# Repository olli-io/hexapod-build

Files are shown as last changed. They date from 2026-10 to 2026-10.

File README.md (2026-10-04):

# hexapod-build

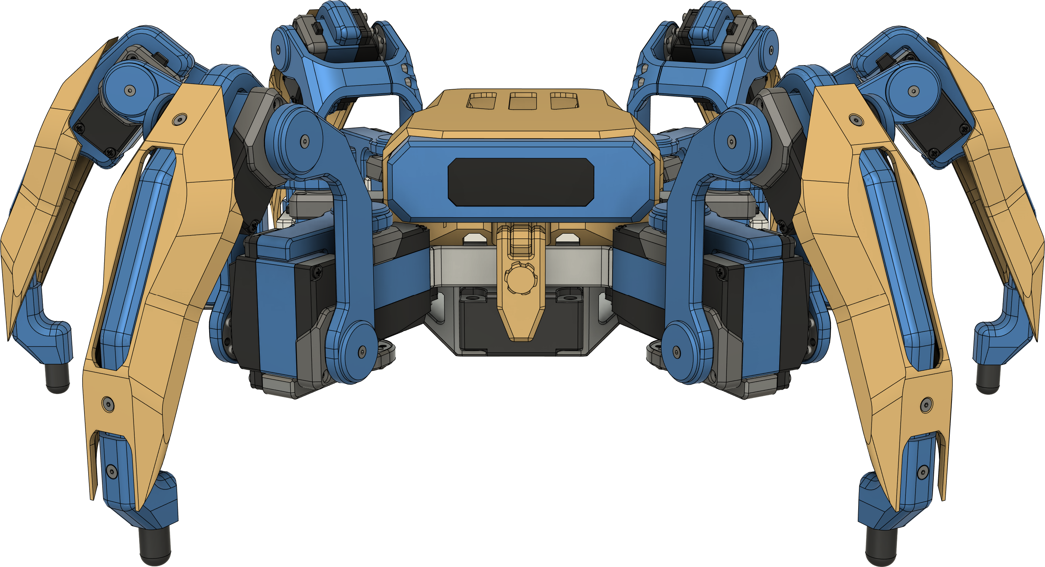
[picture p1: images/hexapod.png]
Hexapod render


## Introduction

This is the main build repository for a hexapod I've designed and built. This and the two companion repositories contain instructions to build and drive the hexapod.

> [!WARNING]
> This is a challenging, purely DIY project. Use these instructions at you own risk. There is no support, warranty or throubleshooting help. If you want to build it, be prepared to do figure out any issues you may run into yourself.
>
> NOTE: A simpler/cheaper build is in the works using a Pi Pico 2 W instead of a rasperry pi.

The hexapod can be controlled with an xbox (or equivalent) controller or a webapp hosted via wifi on the rasperry pi running the robot.

## Resources 

- [`instructions`](instructions-v1.0.0.pdf) - Build instructions
- [`bill-of-materials`](bill-of-materials.md) - Parts list.
- [`prints/`](prints) - Print files (`.3mf`).
- [`cad/`](cad) - CAD models (`.step`).
- [Demo video](https://youtube.com/shorts/dI83HE2yN1Q) - Hexapod in action.

## Companion repositories

The hexapod software is hosted on two repositories, which contain instructions how to get the hexapod running.
- [olli-io/hexapod-ros2-control](https://github.com/olli-io/hexapod-ros2-control) — ROS 2 control stack for the 6-leg / 18-DOF hexapod. Runs in docker on a Raspberry Pi 5. Also includes a Gazebo sim container for linux.
- [olli-io/hexapod-servo2040-driver](https://github.com/olli-io/hexapod-servo2040-driver) — Firmware for the Pimoroni Servo 2040 (RP2040). Drives the 18 servos over UART.

## Contributions

I am open to contributions. Example: if you use your time to modify the leg parts to accomodate a servo with different dimensions, please let me know and we can add it to the repo.

The [MYP hexapod](https://github.com/MakeYourPet/hexapod) and [Aecert's hexapod](https://github.com/Ryan-Mirch/Aecerts_Hexapod_V1) are spiritual predecessors of this project. Ideas have been taken from both of these projects.

> [!NOTE]
> This work is licensed under the [Creative Commons Attribution-NonCommercial 4.0 International License (CC BY-NC 4.0)](https://creativecommons.org/licenses/by-nc/4.0/). See [`LICENSE`](LICENSE).

## Images

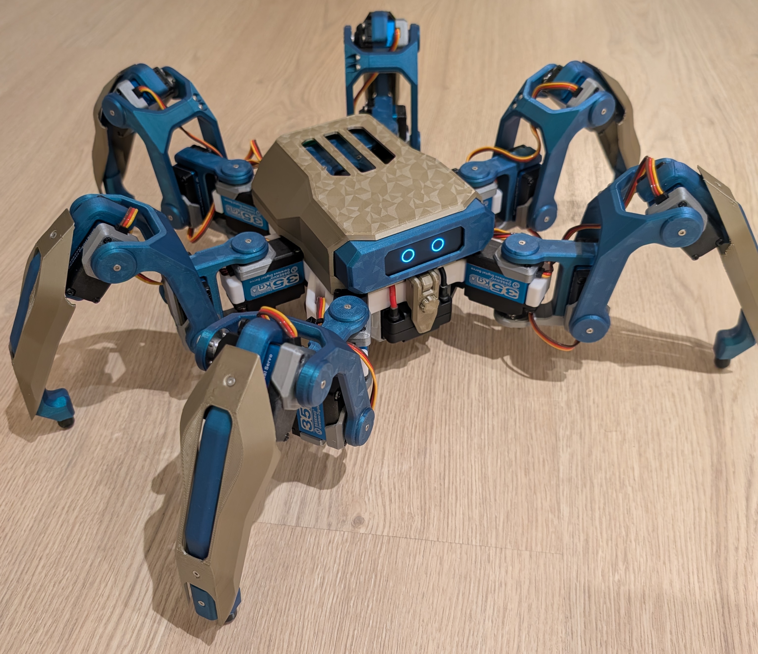
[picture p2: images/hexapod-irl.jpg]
Hexapod in real life


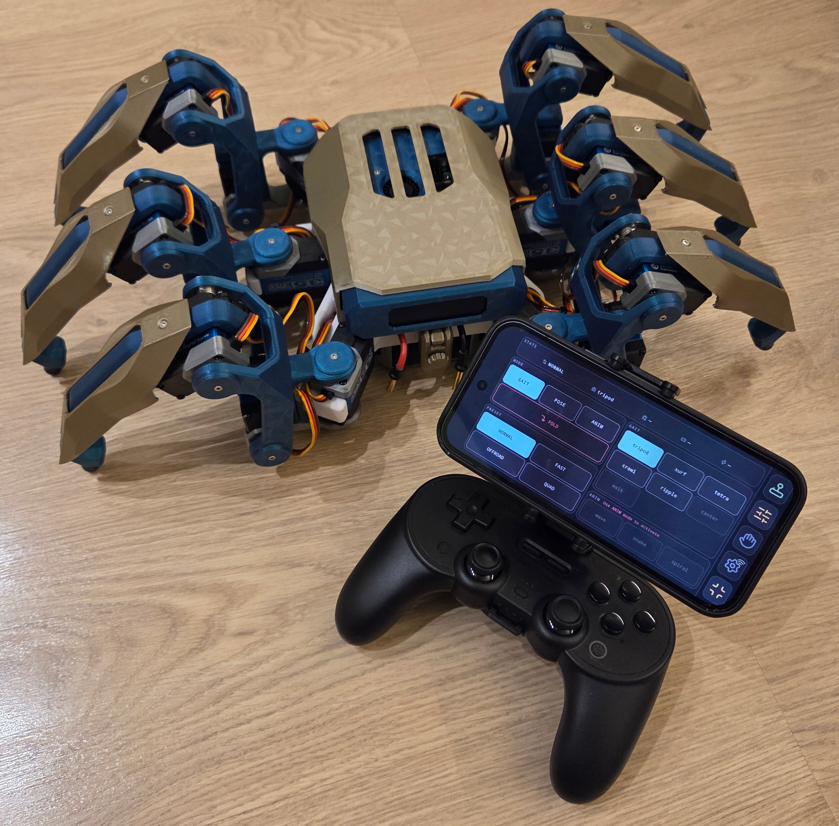
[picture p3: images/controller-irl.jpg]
Controller


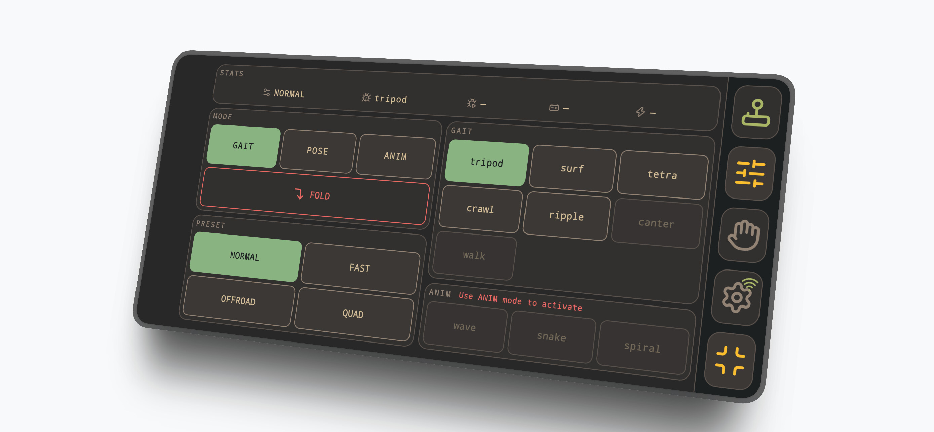
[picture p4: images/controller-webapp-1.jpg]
Controller web app


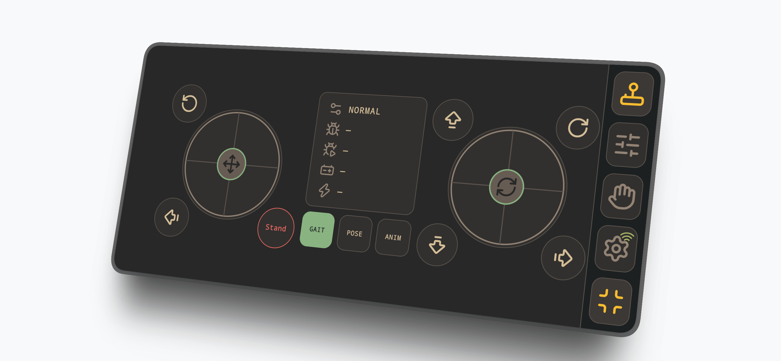
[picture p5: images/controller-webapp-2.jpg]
Controller web app


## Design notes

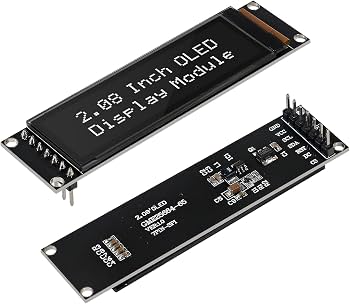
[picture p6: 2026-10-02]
images/oled-display-reference.jpg

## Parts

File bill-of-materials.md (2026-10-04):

# Bill of materials

> [!WARNING]
> Be prepared: this list may not be correct/up to date and something may be missing.
> Note: materials for the microswitch leg tips are not included in this BOM.

**Servos**

- 18 pcs RD3235SG servo
- 18 pcs Metal servo horn

**Screws**

- 18 pcs M2 x 6 hex screw countersunk
- 18 pcs M2 x 10 hex screw countersunk
- 75 pcs M2.5 x 10 hex screw DIN912
- 10 pcs M3 x 10 hex screw DIN912

**Threaded inserts**

- 36 pcs M2x3x3.2 
- 75 pcs M2.5x6x3.5
- 35 pcs M3x6x5

**Electronics**

- 1 pcs Pimoroni Servo 2040
- 1 pcs Raspberry Pi 5, 2 GB minimum.  
- 1 pcs Single channel relay, 5 V
- 1 pcs 2.08 inch, 256x64 SH1122 oled display ([reference](images/oled-display-reference.jpg))
- 1 pcs 5v, 5A Ubec
- 1 pcs MTS-101 toggle switch
- 2 pcs 4 mm bullet connector (when using a 4mm connector battery)
- 1 pcs usb type-c male breakout/test board
- 1 m AWG16 wire red
- 1 m AWG16 wire black
- 1 m AWG20 wire red
- 1 m AWG20 wire black
- Gpio jumper wires, female-female, various colors
- 1x40pin 2.54mm male pin headers
- Heatshrink, various ID

**Battery and charger**

- 1 pcs ~6000 mAh 2S LiPo, hard case , 4 mm bullet connectors
- 1 pcs LiPo charger

**Misc**
- 6 pcs (as pictured) rubber vacuum caps, ~6mm ID
- 6 pcs (alternative) clothes hanger rubber end caps, 6mm ID
- 2 kg PLA or PETG filament
- 5 ml normal/blue loctite

**Tools(required)**

- Soldering iron
- Wire cutter
- Wire stripper
- 3D printer, build area > 24 cm
- M2, M2.5, M3 hex keys
- Phillips head screwdriver

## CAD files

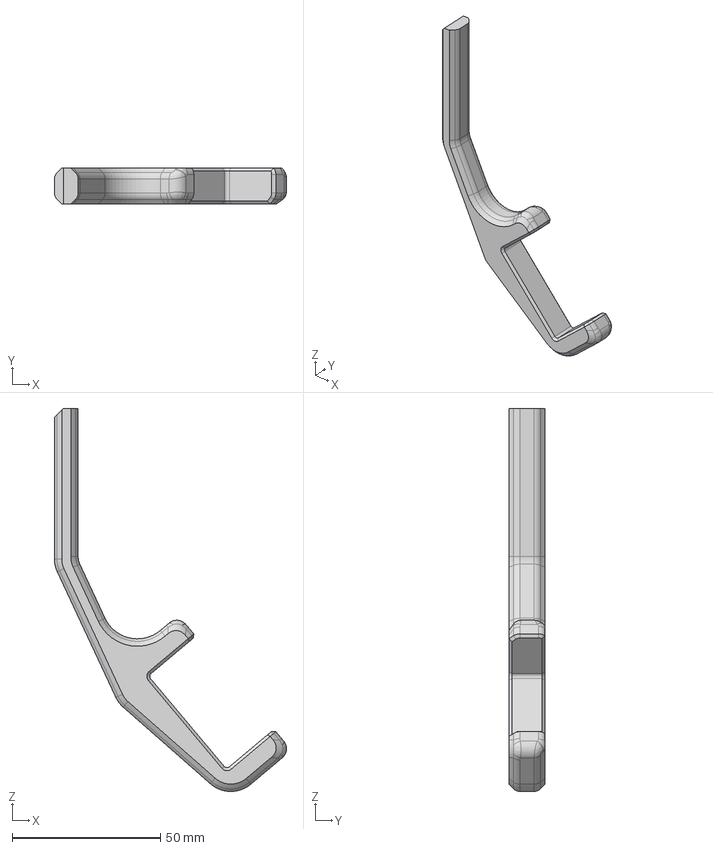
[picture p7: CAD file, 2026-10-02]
cad/legs/tibia/tibia-main-left-x3.step
78.2 x 12.2 x 129.0 mm

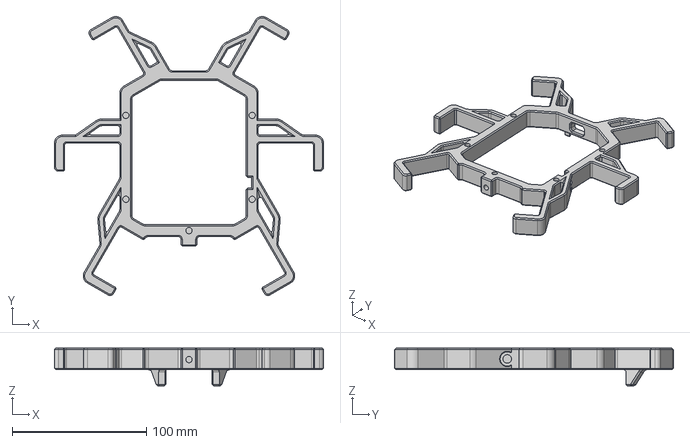
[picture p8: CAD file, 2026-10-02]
cad/body/frame-main-x1.step
200.3 x 207.6 x 28.0 mm

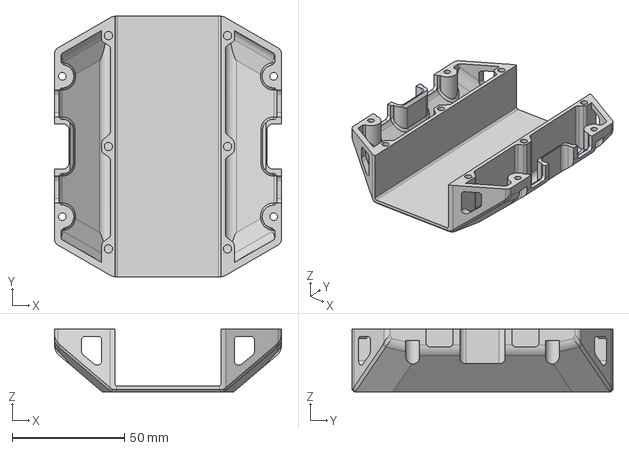
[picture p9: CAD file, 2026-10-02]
cad/body/bottom-cover-main-x1.step
101.0 x 116.1 x 27.9 mm

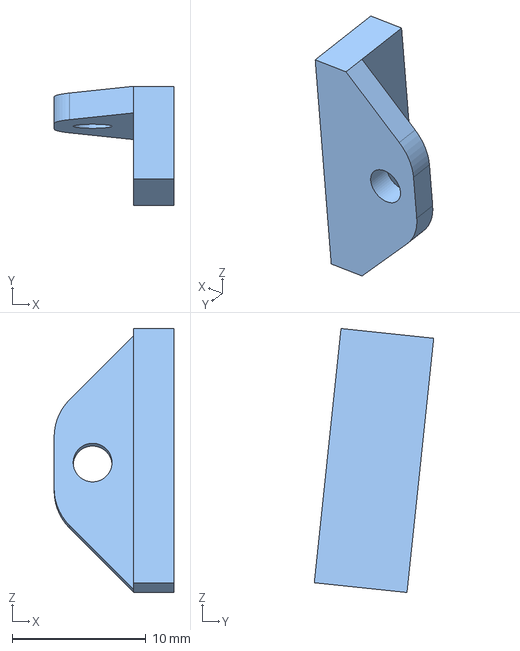
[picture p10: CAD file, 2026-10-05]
cad/body/display-clamp.step
8.95 x 8.93 x 19.7 mm

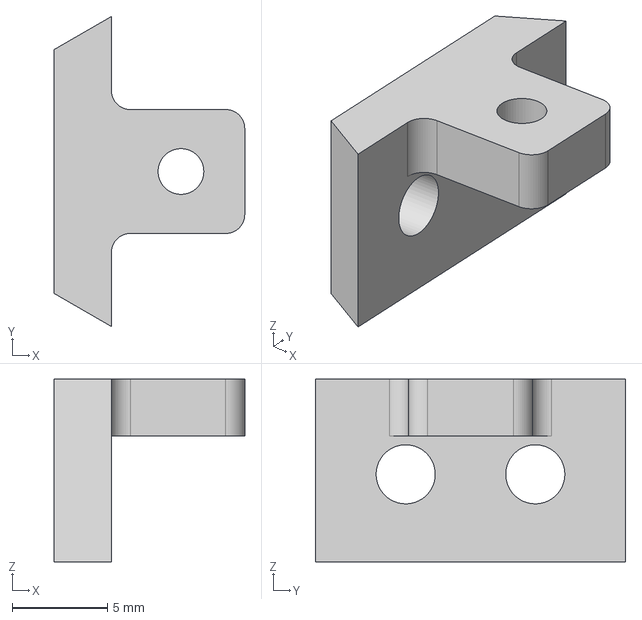
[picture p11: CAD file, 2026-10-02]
cad/body/rpi4-attachments/micro-switch-mount-x1.step
10.0 x 16.3 x 9.60 mm

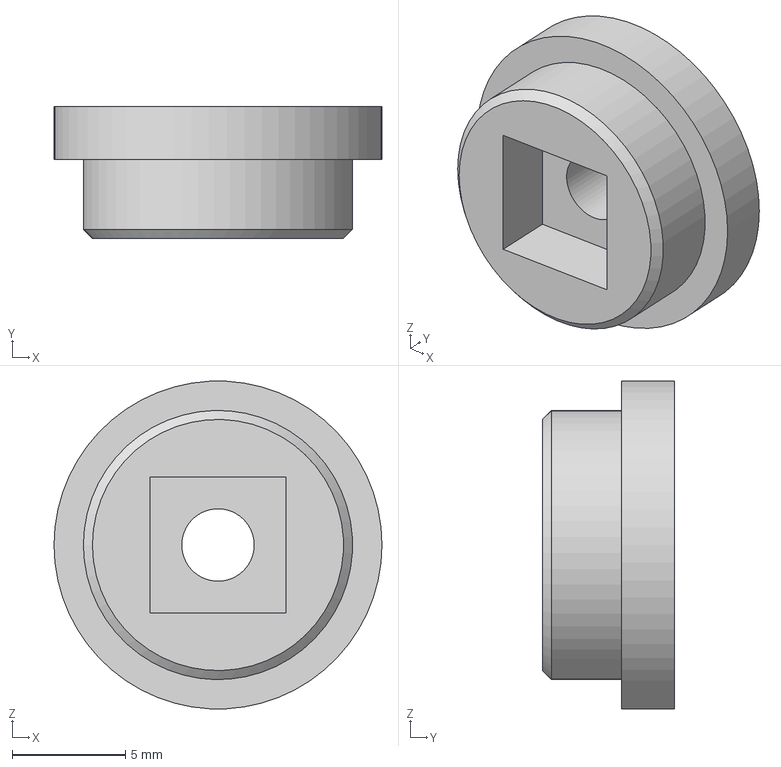
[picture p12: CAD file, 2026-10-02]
cad/legs/common/servo-shaft-x18.step
14.5 x 5.85 x 14.5 mm

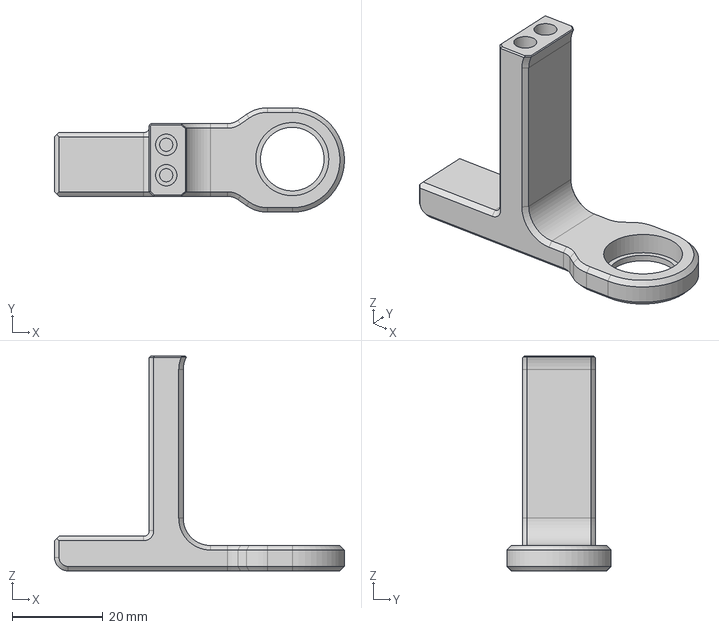
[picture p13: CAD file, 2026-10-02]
cad/legs/coxa/coxa-top-left-x3.step
63.8 x 23.0 x 47.3 mm

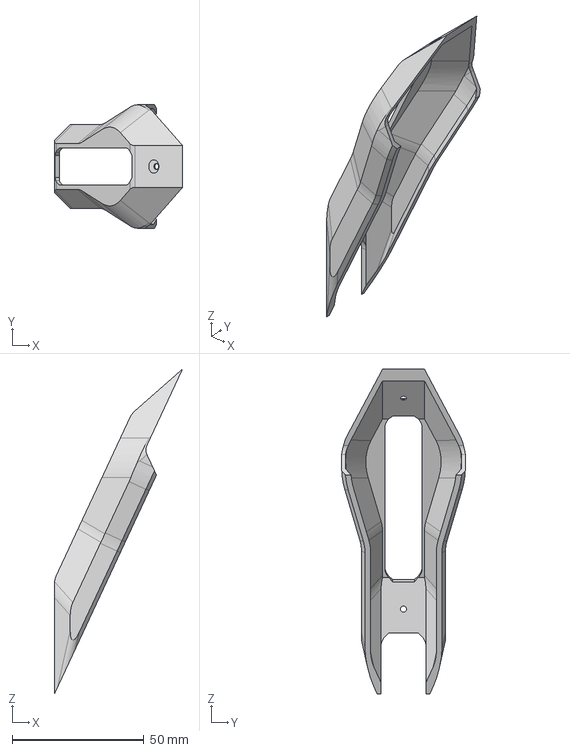
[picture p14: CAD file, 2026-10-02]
cad/legs/tibia/shield-x6.step
48.7 x 47.0 x 123.6 mm

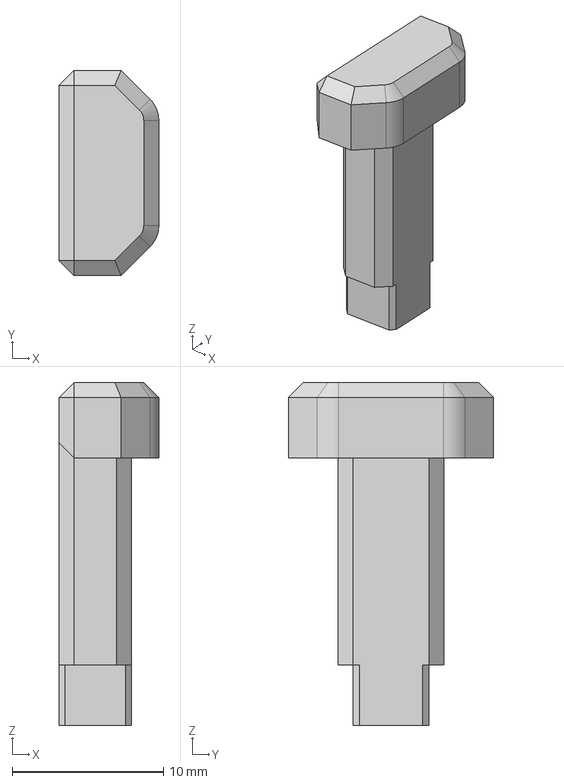
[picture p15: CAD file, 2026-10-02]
cad/legs/tip/alternative-touch-sensor/slider-shaft-x6.step
6.60 x 13.6 x 22.7 mm

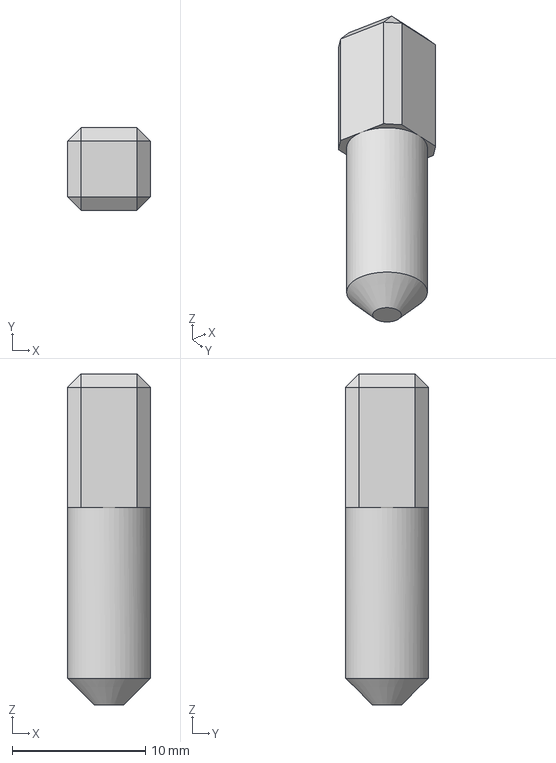
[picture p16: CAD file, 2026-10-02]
cad/legs/tip/tip-shaft-x6.step
6.20 x 6.20 x 24.8 mm

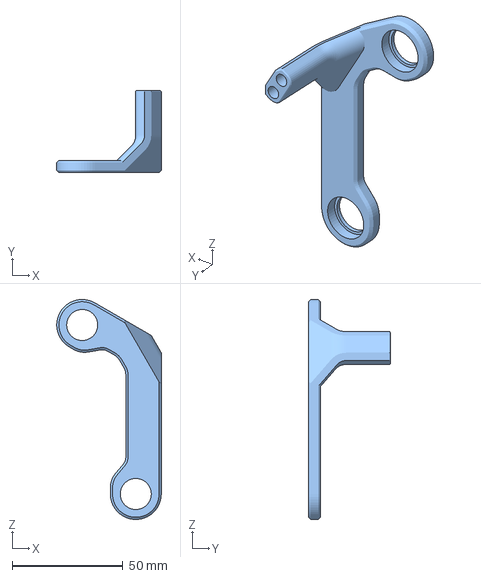
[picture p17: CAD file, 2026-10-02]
prints/legs/femur/femur-bushing-side-right-x3.3mf
47.2 x 37.0 x 99.2 mm

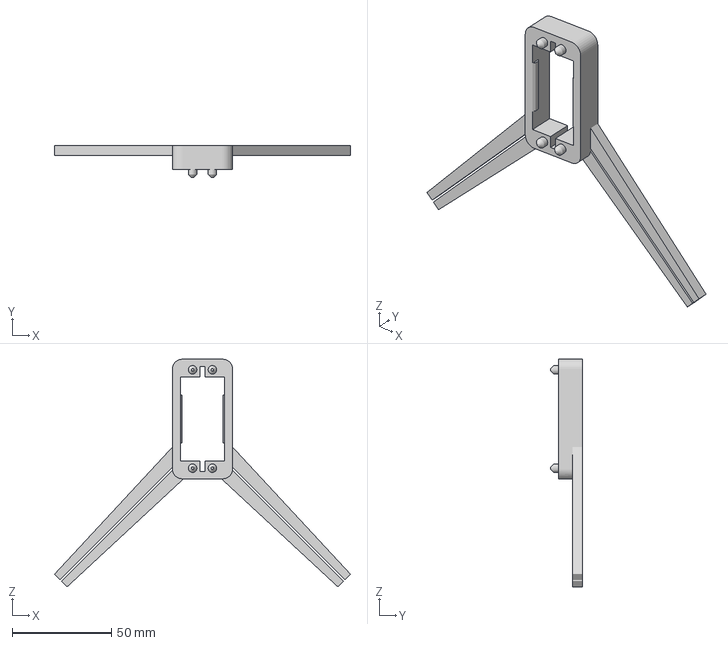
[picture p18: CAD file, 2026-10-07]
prints/utils/calibration-mount.3mf
149.2 x 16.0 x 114.7 mm

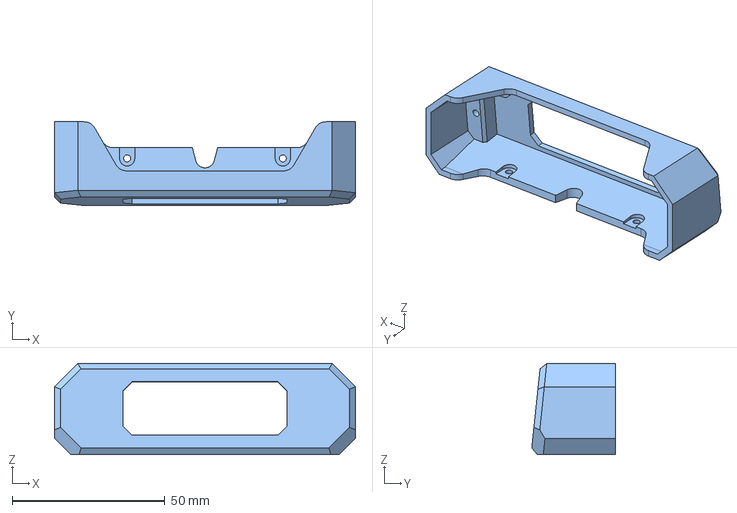
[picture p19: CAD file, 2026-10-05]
cad/body/display-frame.step
98.6 x 27.4 x 29.8 mm

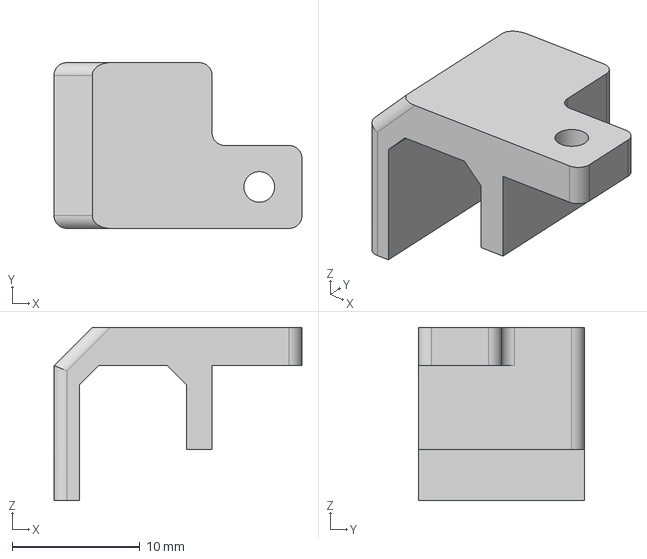
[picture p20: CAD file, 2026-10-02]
cad/body/rpi4-attachments/cable-manager-x1.step
19.5 x 13.0 x 13.6 mm

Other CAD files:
cad/legs/tibia/tibia-main-right-x3.step
cad/legs/common/bushing-x18.step
cad/legs/coxa/coxa-top-right-x3.step
cad/legs/tip/alternative-touch-sensor/switch-cover-x6.step
cad/body/hardware-plate-x1.step
cad/body/lipo-latch-x1.step
cad/body/rpi-mount-x1.step
cad/body/rpi4-attachments/buzzer-mount-x1.step
cad/body/thumb-screw-x1.step
cad/body/top-x1.step
cad/legs/common/bolt-washer-x36.step
cad/legs/common/friction-adjuster-x18.step
cad/legs/common/servo-shaft-mount-x18.step
cad/legs/coxa/coxa-bottom-left-x3.step
cad/legs/coxa/coxa-bottom-right-x3.step
cad/legs/tip/alternative-touch-sensor/footpad-x6.step
cad/legs/tip/alternative-touch-sensor/switch-frame-x6.step
cad/legs/tip/tip-frame-x6.step
prints/body/bottom-cover-main-x1.3mf
prints/body/display-clamp.3mf
prints/body/display-frame.3mf
prints/body/frame-main-x1.3mf
prints/body/hardware-plate-x1.3mf
prints/body/lipo-latch-x1.3mf
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

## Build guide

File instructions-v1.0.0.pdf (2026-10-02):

## Olli-io’s hexapod – build instructions (v1.0.0)

V1.0.1

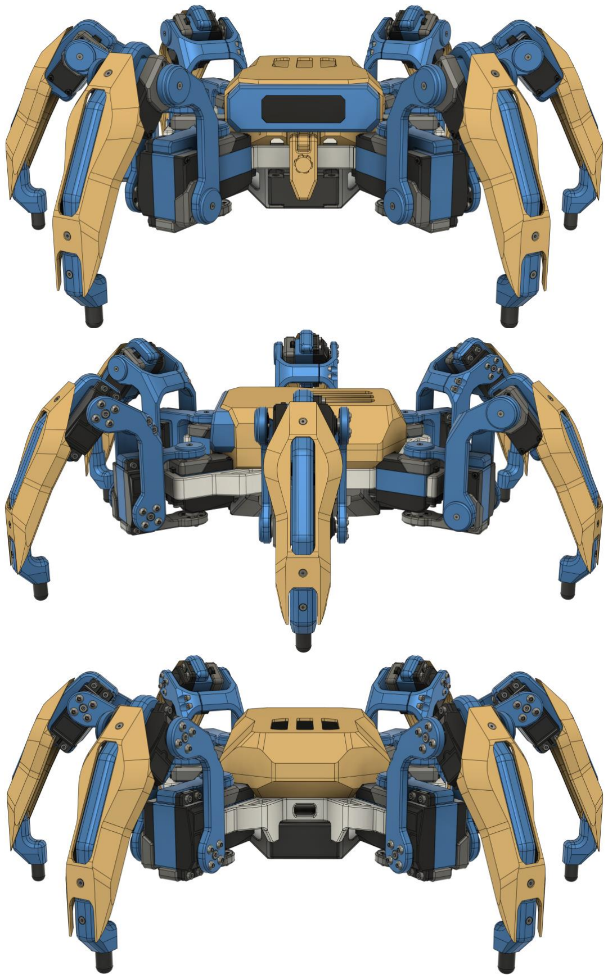
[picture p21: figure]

## Notes

ds3235sg →

servo-horn →

M3x6 mm →

1) Attach servo to servo controller or servo2040 (servoCalibration.uf2)
2) Move servo to the middle position (1500 ms).
3) Attach servo horn so that holes are aligned as pictured and mark the direction of the servo horn. Note: due to the way servos are assembled, you can typically never align the servo horn exactly, this is why we are doing the calibration.
4) Using either a separate servo calibrator or a servo2040 board with the servo calibration firmware loaded (recommended option), collect +45° and -45° values using a servo calibrator or a servo2040 with calibrations firmware. Make sure to mark the servos with numbers so that you can later match the calibrated values.
5) How to calibrate servos using the servo2040: https://github.com/olli (https://github.com/olli-io/hexapod-servo2040-driver/blob/master/src/servoCalibration/README.md)-io/hexapod (https://github.com/olli-io/hexapod-servo2040-driver/blob/master/src/servoCalibration/README.md)- (https://github.com/olli-io/hexapod-servo2040-driver/blob/master/src/servoCalibration/README.md)servo2040 (https://github.com/olli-io/hexapod-servo2040-driver/blob/master/src/servoCalibration/README.md)- (https://github.com/olli-io/hexapod-servo2040-driver/blob/master/src/servoCalibration/README.md)driver/blob/master/src/servoCalibration/README.md (https://github.com/olli-io/hexapod-servo2040-driver/blob/master/src/servoCalibration/README.md)
- calib-arm
- calib-ruler

-45°
+45°

## A. Servo calibration (x 18)

1) This is a fairly complex open source DIY hexapod. The models, code and instruction are free. No support or quarantee is provided. Mistakes or errors in the BOM or instructions can be submitted via github issues.
2) To build the hexapod, you need the materials listed in the BOM and the following tools: M2, M2.5, M3 hex keys, 3D-printer and soldering iron. For servo calibration, either a manual servo calibrator or a pimoroni servo2040 board are required.
3) The instructions contain two alternative leg tip assemblies (D-1 and D-2). It is recommended to build the hexapod using the simpler leg tips. The sensors are currently _not_ used in the ROS 2 controller software. Only build the sensor legs if you plan to implement them in you own hexapod or you are coding your own locomotion/gait platform. The D-2 leg tip also SUCKS and needs a redesign!
4) Good luck and have fun!

## B. Servo assembly × 18

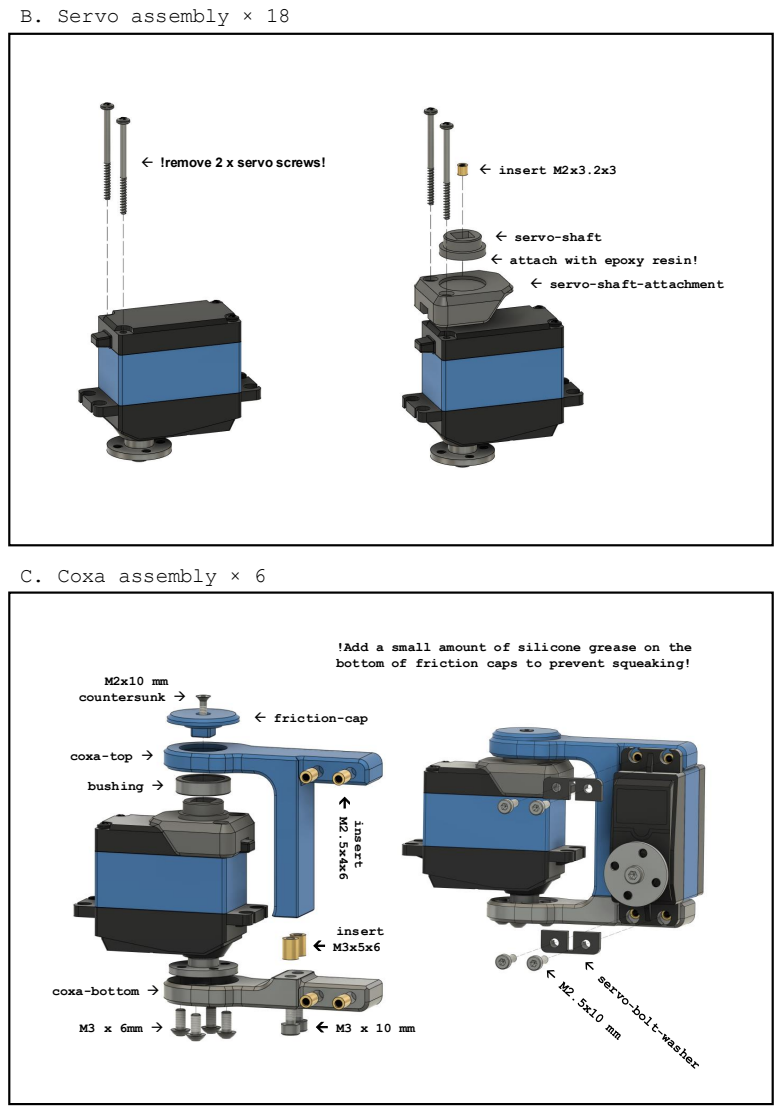
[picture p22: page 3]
!remove 2 x servo screws!; insert M2x3.2x3; servo-shaft; C. Coxa assembly × 6; M2x10 mm countersunk →; friction-cap; bushing →; coxa-top →; coxa-bottom →; insert M3x5x6

attach with epoxy resin!

servo-shaft-attachment

!Add a small amount of silicone grease on the
bottom of friction caps to prevent squeaking!
M3 x 10 mm insert

## D-1. Tip assembly × 6 (RECOMMENDED)

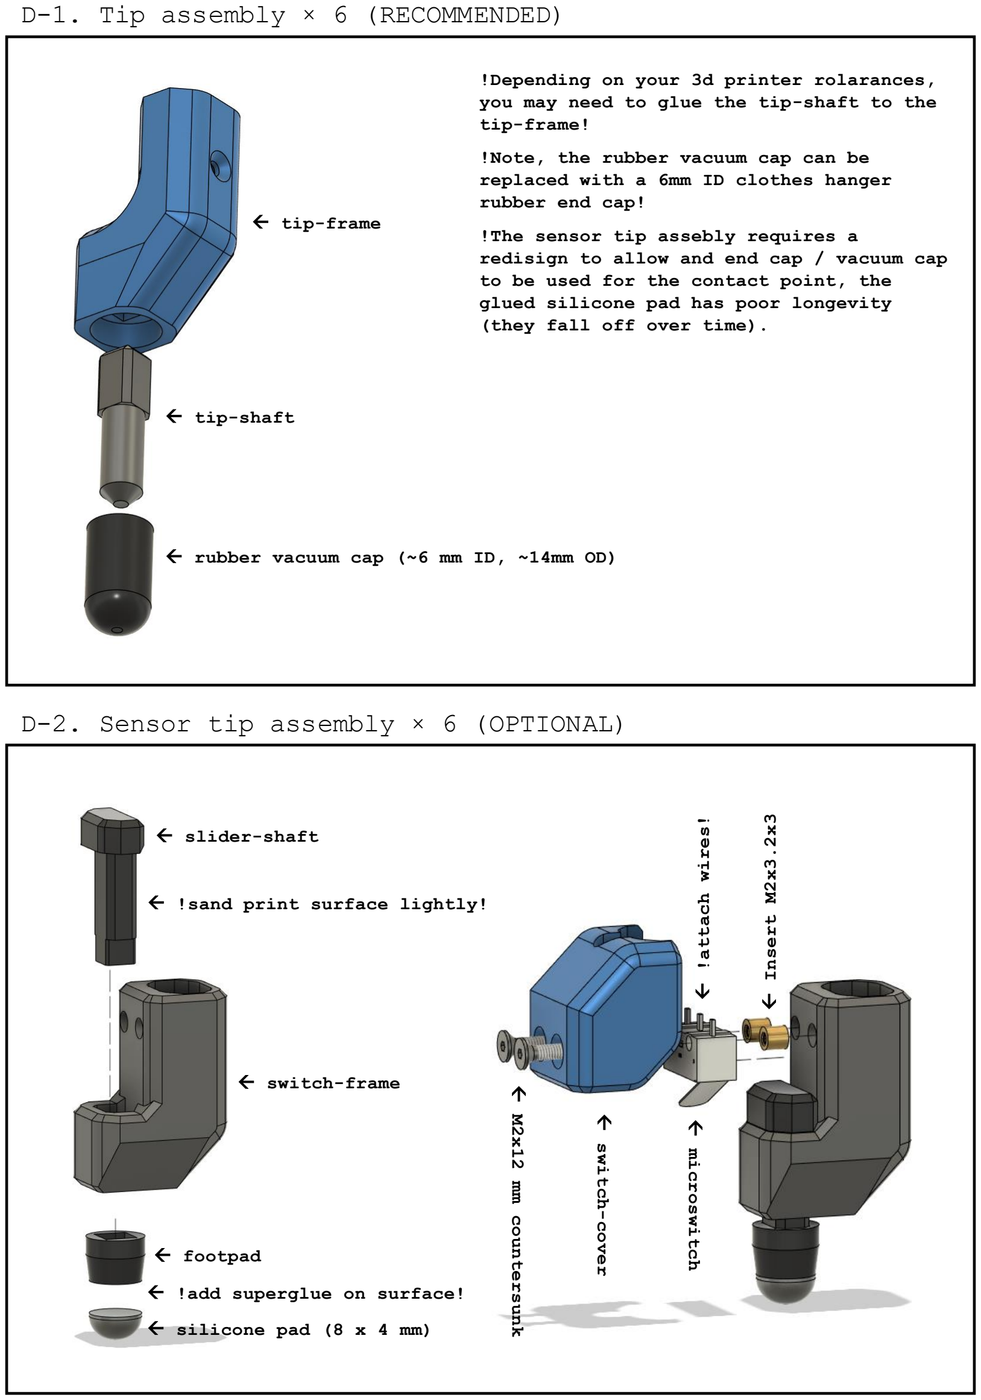
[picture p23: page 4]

- silicone pad (8 x 4 mm)
- footpad
- switch-frame
- slider-shaft
- !sand print surface lightly!
- !add superglue on surface!

### - switch-cover

microswitch

### - M2x12 mm countersunk

### - Insert M2x3.2x3 - !attach wires!

## D-2. Sensor tip assembly × 6 (OPTIONAL)

- tip-frame
- rubber vacuum cap (~6 mm ID, ~14mm OD)
- tip-shaft

!Depending on your 3d printer rolarances, you may need to glue the tip-shaft to the tip-frame!

!Note, the rubber vacuum cap can be replaced with a 6mm ID clothes hanger rubber end cap!

!The sensor tip assebly requires a redisign to allow and end cap / vacuum cap to be used for the contact point, the glued silicone pad has poor longevity (they fall off over time).

## E. Tibia assembly × 6

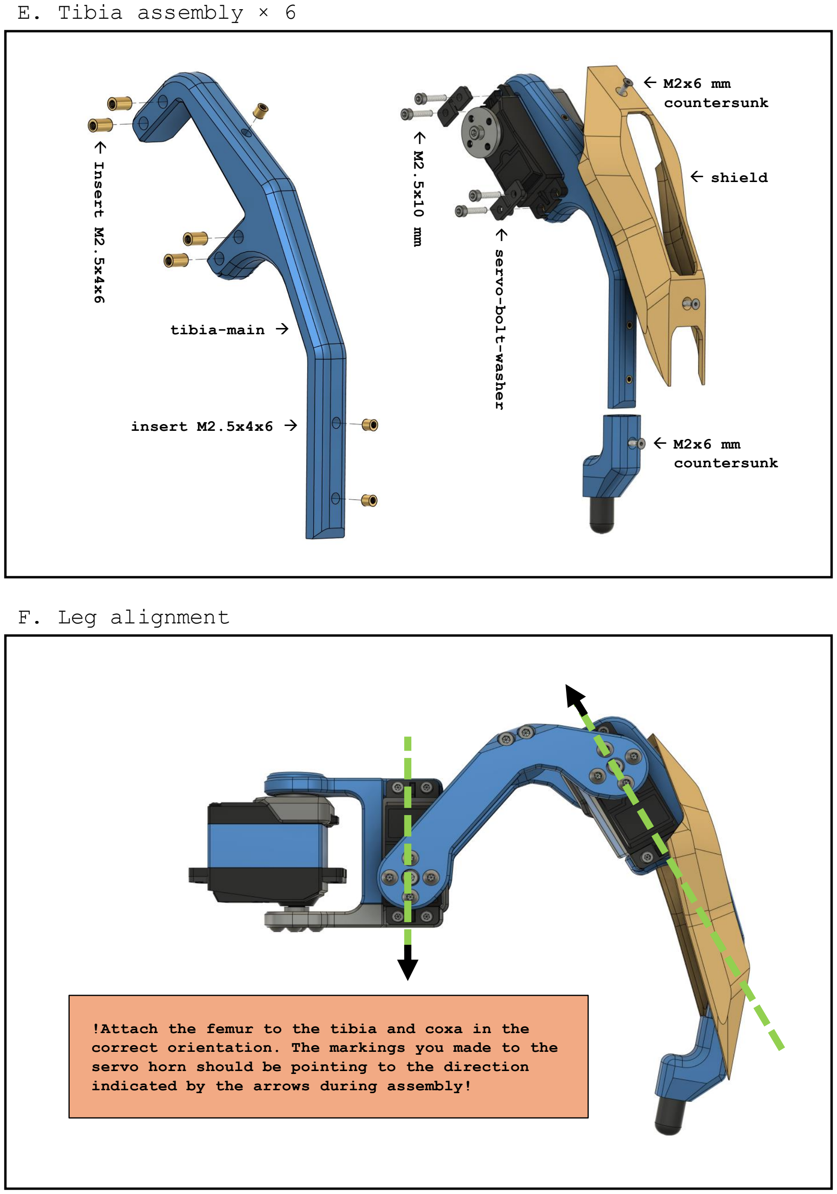
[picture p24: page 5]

## F. Leg alignment

!Attach the femur to the tibia and coxa in the correct orientation. The markings you made to the servo horn should be pointing to the direction indicated by the arrows during assembly!

### - Insert M2.5x4x6

insert M2.5x4x6 →

tibia-main →

### - M2.5x10 mm

### - servo-bolt-washer

- shield
- M2x6 mm
countersunk
- M2x6 mm
countersunk

# G. Leg assembly × 6 M2x10 mm

### !NOTE: servos need to be calibrated before attaching the

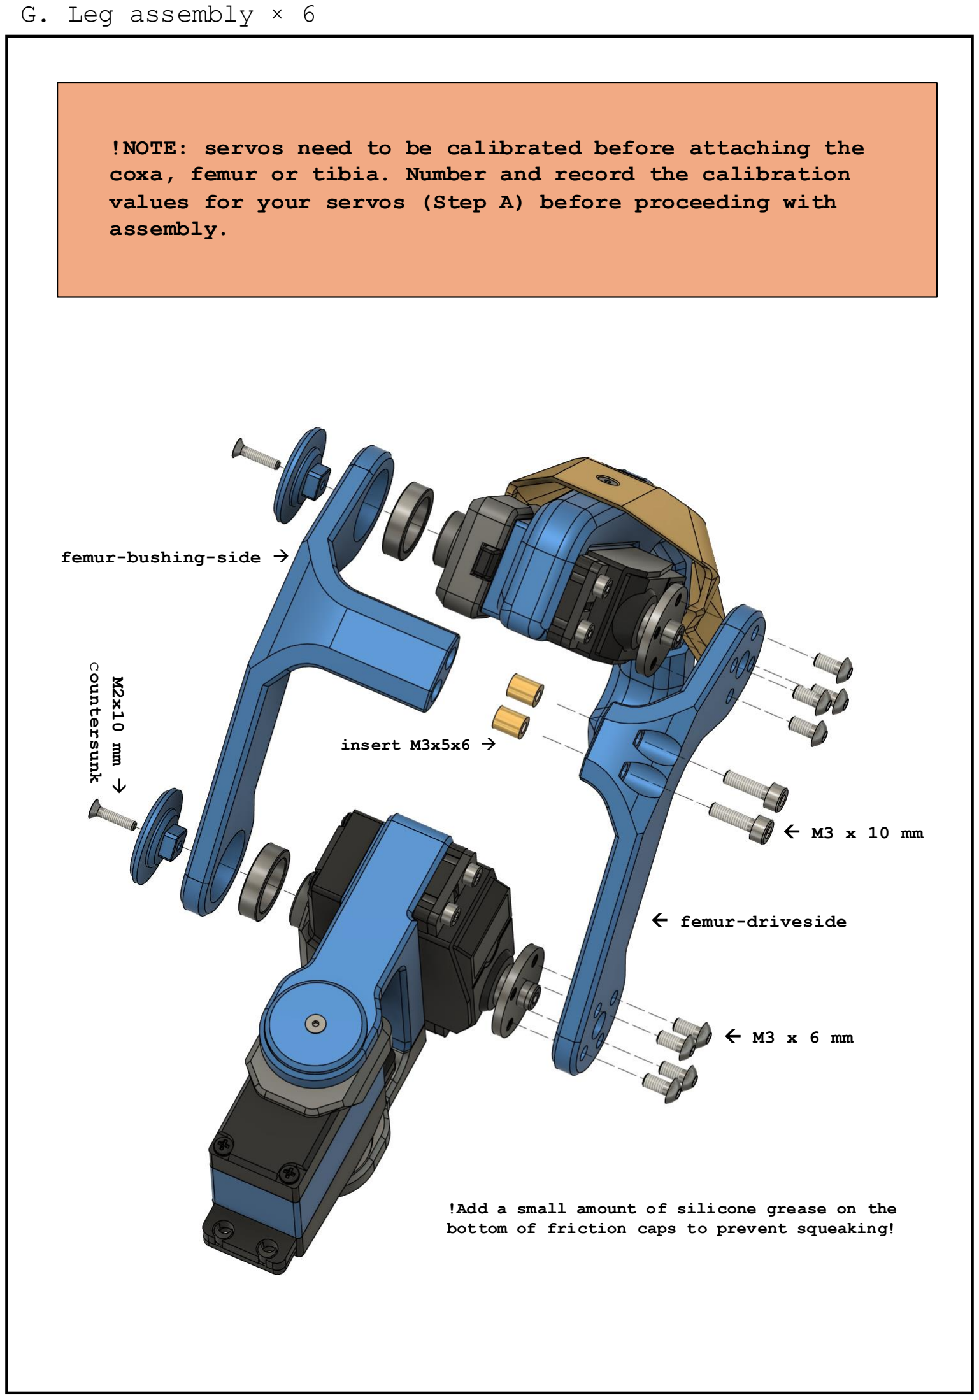
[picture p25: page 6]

→

countersunk

femur-bushing-side →

- M3 x 6 mm
- femur-driveside
- M3 x 10 mm

insert M3x5x6 →

!Add a small amount of silicone grease on the bottom of friction caps to prevent squeaking!

### coxa, femur or tibia. Number and record the calibration values for your servos (Step A) before proceeding with

assembly.

## H. Frame assembly

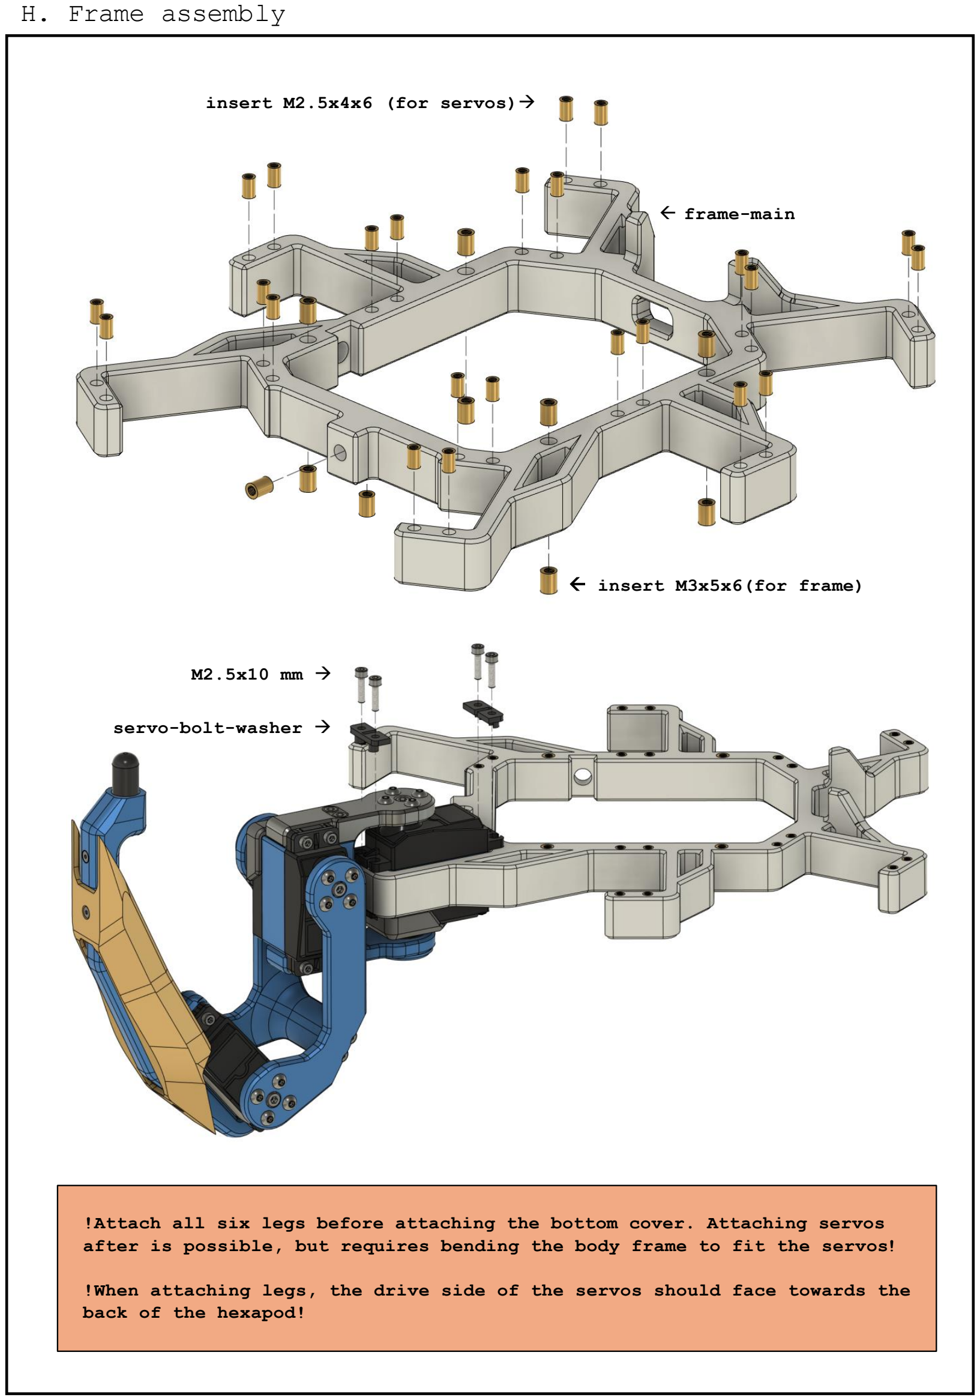
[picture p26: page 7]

- frame-main

insert M2.5x4x6 (for servos)→

- insert M3x5x6(for frame)

M2.5x10 mm →

servo-bolt-washer →

!Attach all six legs before attaching the bottom cover. Attaching servos after is possible, but requires bending the body frame to fit the servos!

!When attaching legs, the drive side of the servos should face towards the back of the hexapod!

## H. Bottom cover & servo controller

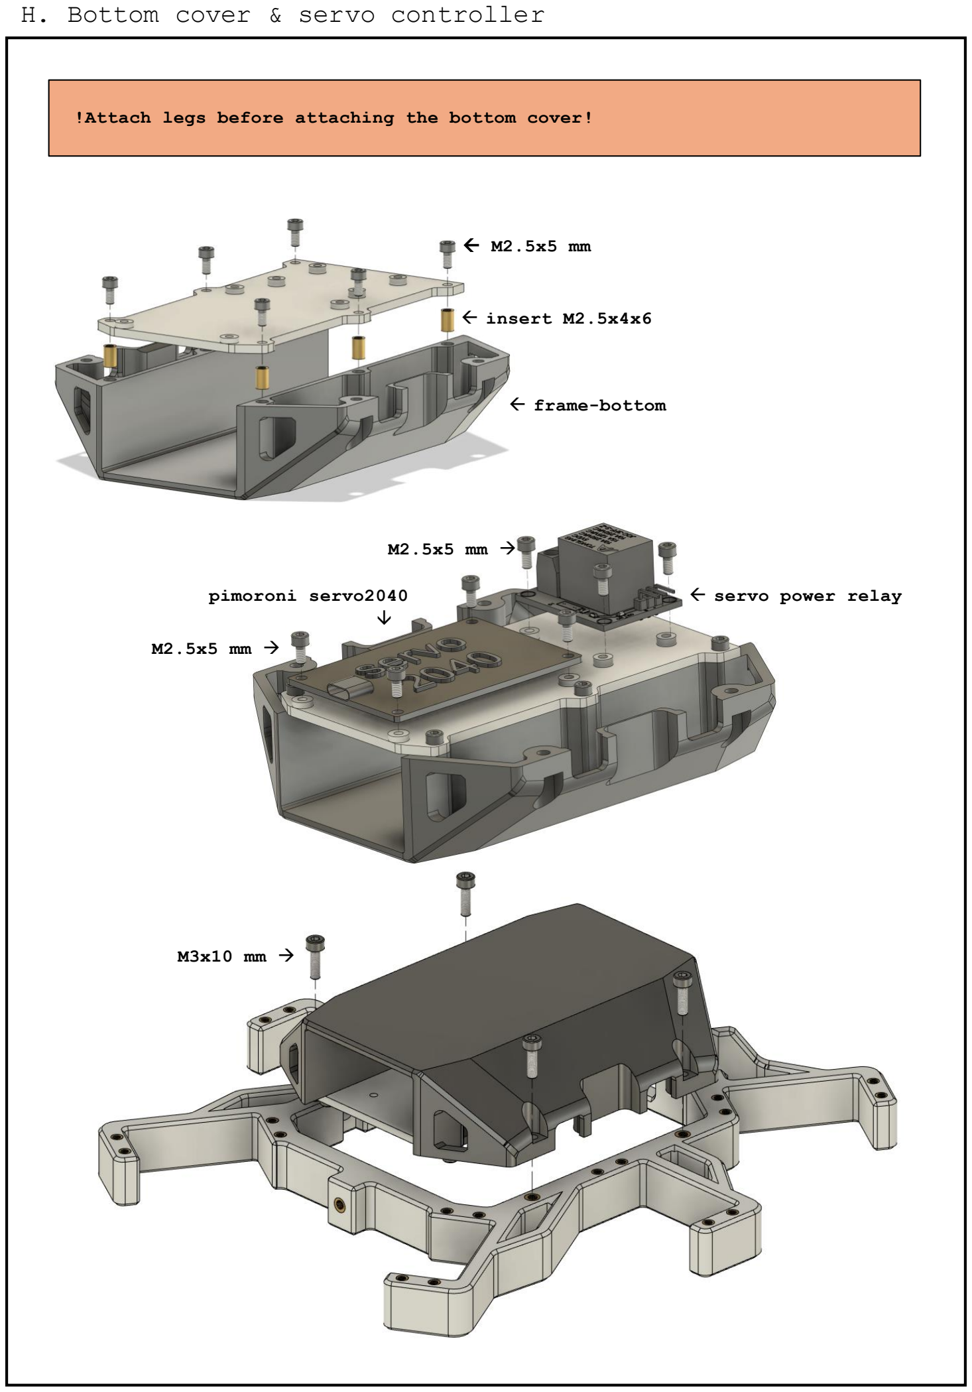
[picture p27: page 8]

- M2.5x5 mm
- insert M2.5x4x6
- frame-bottom

M3x10 mm →

M2.5x5 mm →

M2.5x5 mm →

pimoroni servo2040
→
- servo power relay

!Attach legs before attaching the bottom cover!

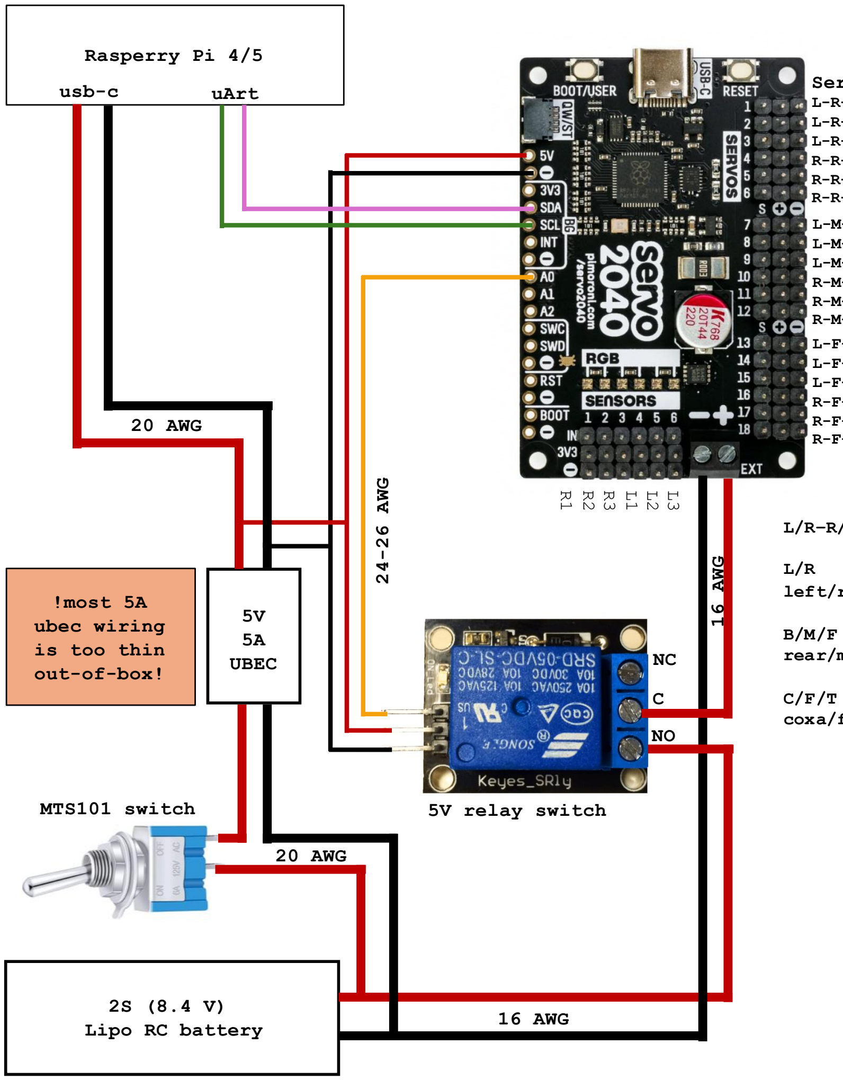
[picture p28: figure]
!most 5A; ubec wiring; is too thin out-of-box!; MTS101 switch; 5V relay switch; Lipo RC battery; 5A UBEC; Rasperry Pi 4/5; uArt; usb-c; 16 AWG; 20 AWG; 24-26 AWG

Servos:
L-R-C
L-R-F
L-R-T
R-R-C
R-R-F
R-R-T

L-F-C
L-F-F
L-F-T
R-F-C
R-F-F
R-F-T

L-M-C
L-M-F
L-M-T
R-M-C
R-M-F
R-M-T

## H-1. Servo controller wiring

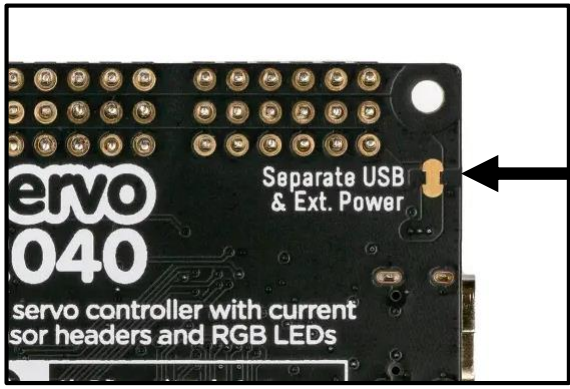
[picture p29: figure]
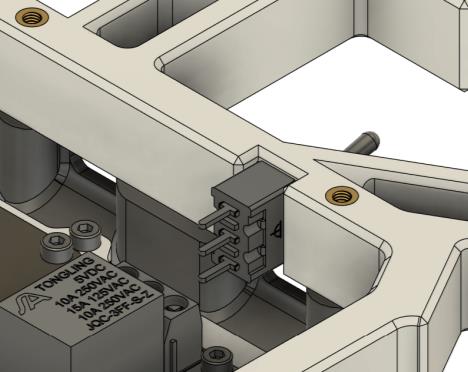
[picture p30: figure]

!CUT THIS!

...or your
servo2040
will burn

L/R–R/M/F–C/F/T

left/right

rear/middle/front

coxa/femur/tibia

## H-2. Servo controller wiring

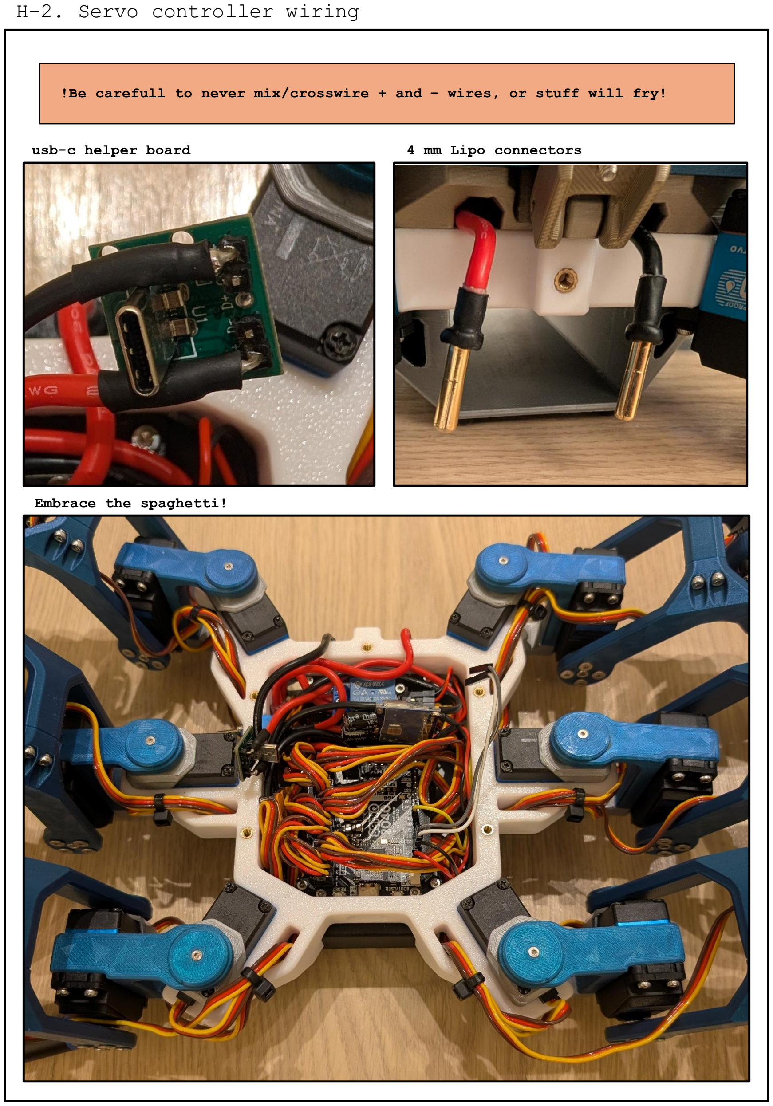
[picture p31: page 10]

usb-c helper board | 4 mm Lipo connectors

Embrace the spaghetti!

!Be carefull to never mix/crosswire + and – wires, or stuff will fry!

## H. Raspberry Pi mounting assembly

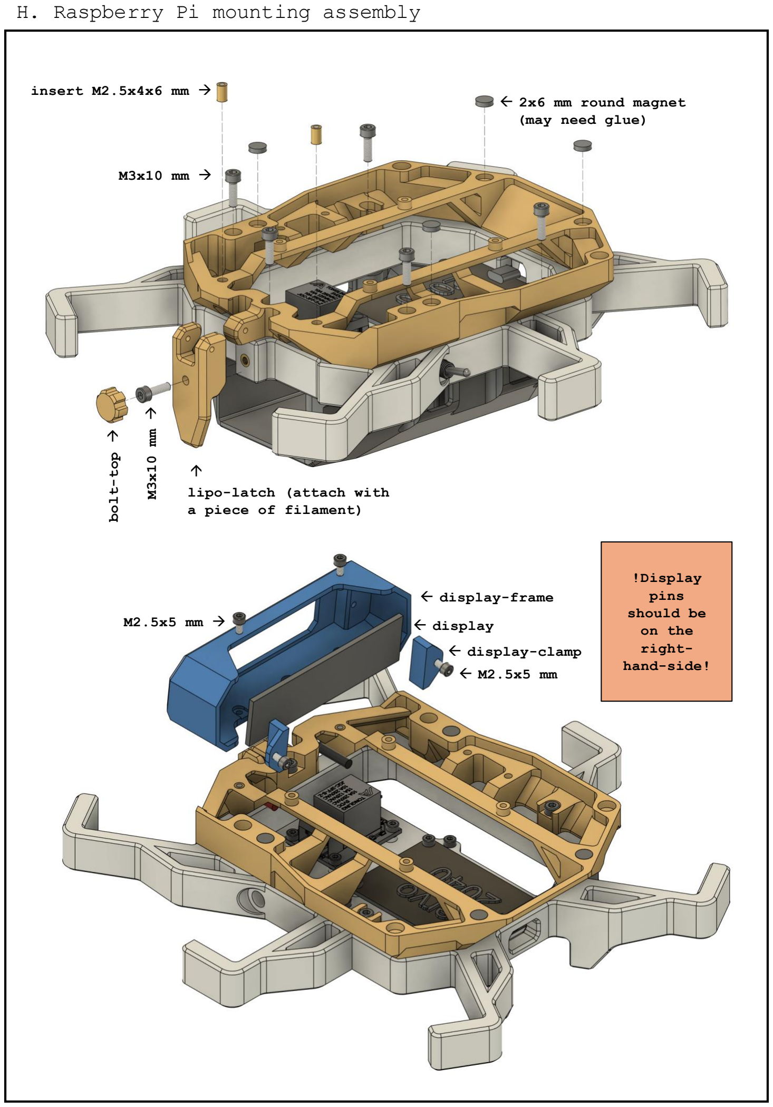
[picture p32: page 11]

insert M2.5x4x6 mm →
- 2x6 mm round magnet
(may need glue)

M3x10 mm →

M3x10 mm

→

bolt-top

→

→

lipo-latch (attach with
a piece of filament)
- display-frame
- display
- display-clamp
- M2.5x5 mm

M2.5x5 mm →

!Display
pins
should be
on the
righthand-side!

## H. Raspberry Pi mounting assembly

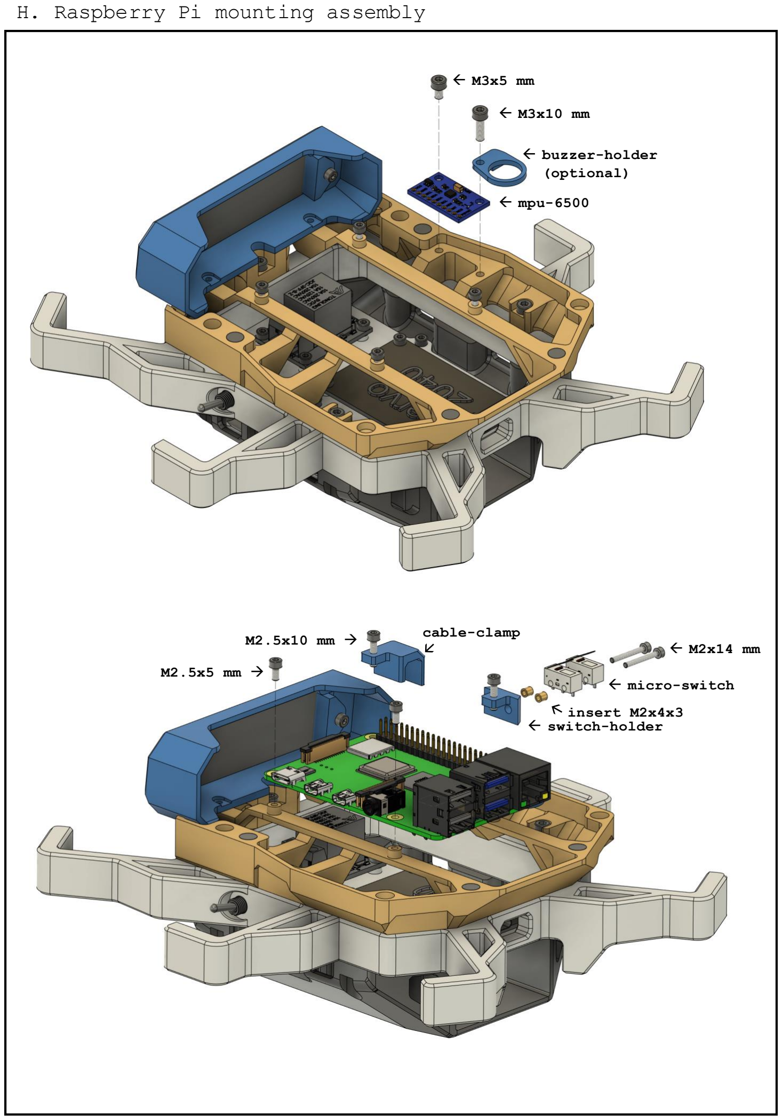
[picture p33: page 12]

M2.5x10 mm →

M2.5x5 mm →

cable-clamp

- switch-holder

insert M2x4x3

- micro-switch
- M2x14 mm
- M3x5 mm
- M3x10 mm
- buzzer-holder
(optional)
- mpu-6500

## H-1. Servo controller wiring

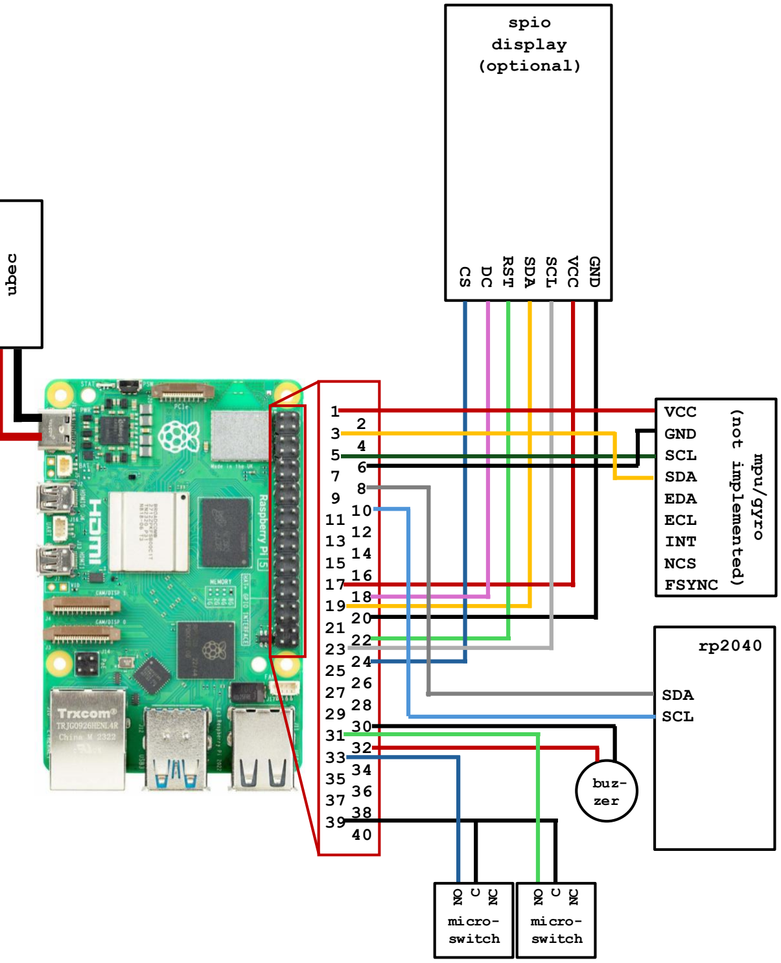
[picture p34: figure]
mpu/gyro; (not implemented); spio; display (optional); ubec; RST; SDA; SCL; VCC; GND; SDA SCL; micro- switch; buz- zer; GND SCL; EDA; ECL; INT; NCS; FSYNC

!The hexapod can be ran and operated without the buzzer, micro-switches, the mpu and the display! All of those are technically optional!

!Display + buttons are used to manage bluetooth connections, wifi setting, etc. These can also be managed via ssh from a terminal!

!20 AWG wires from usb-c to ubec, otherwise regular gpio jumper wires can be used!

## H-1. Servo controller wiring

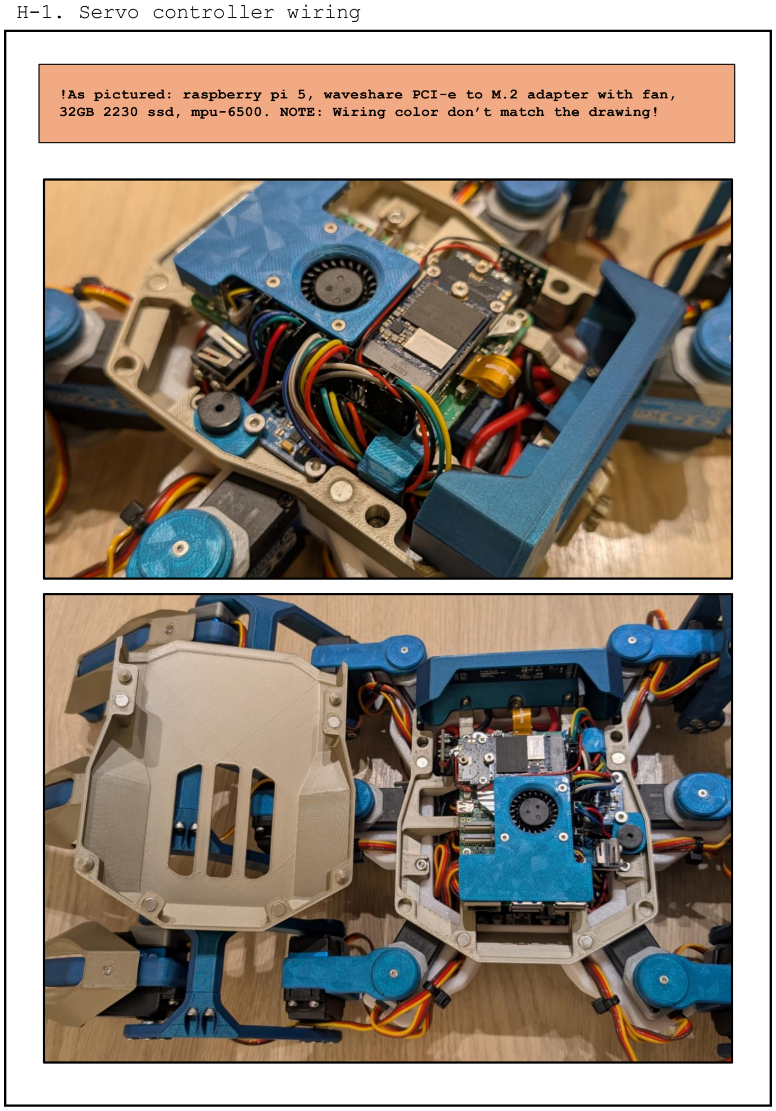
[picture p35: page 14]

!As pictured: raspberry pi 5, waveshare PCI-e to M.2 adapter with fan, 32GB 2230 ssd, mpu-6500. NOTE: Wiring color don’t match the drawing!

## I. Top cover

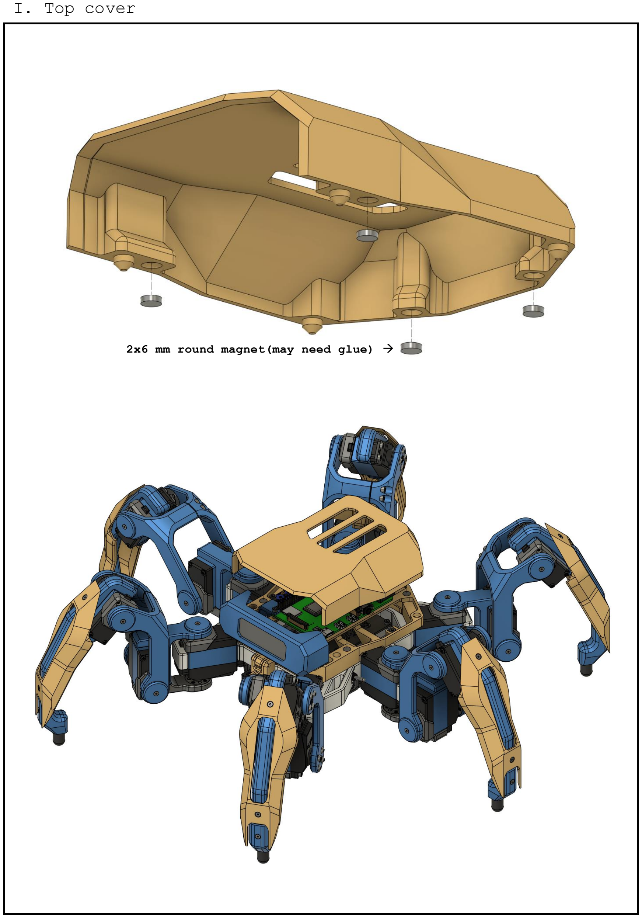
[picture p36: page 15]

2x6 mm round magnet(may need glue) →

## J. Complete!

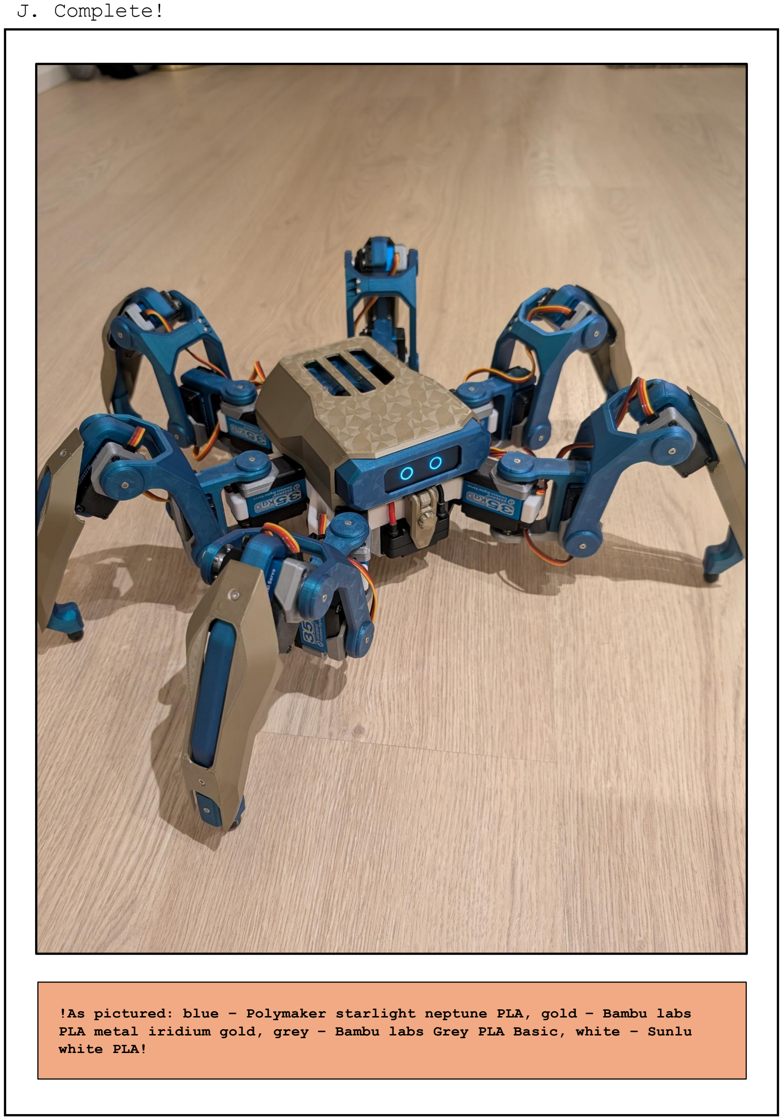
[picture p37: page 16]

!As pictured: blue – Polymaker starlight neptune PLA, gold – Bambu labs PLA metal iridium gold, grey – Bambu labs Grey PLA Basic, white – Sunlu white PLA!

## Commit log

2026-10-02 chore: initial commit
    [bolt-washer-x36.3mf, bolt-washer-x36.step, bottom-cover-main-x1.3mf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]
2026-10-04 docs: update bom
2026-10-04 docs: bom link
2026-10-05 fix: add missing print files
    [display-clamp.3mf, display-clamp.step, display-frame.3mf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]
2026-10-07 feat: add calibration tool print files
    [calibration-arm.3mf, calibration-mount.3mf]
2026-10-20 chore: add fan cover files
2026-10-20 chore: reorganize print and cad files
